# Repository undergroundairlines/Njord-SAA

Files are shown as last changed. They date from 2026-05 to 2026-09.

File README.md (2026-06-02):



# Njord-SAA
The Njord SAA (Submersible Amphibius Aircraft) is a submersible aircraft which can transition automatically from underwater travel to aerial flight. To resurface, it can empty it's 2 ballast tanks, pitch almost 90° directly up, and launch itself above the surface. When the surface is breached, it deploys 2 sets (yes, that means 4 wings total) of wings, and switches motors to a much higher RPM to produce enough thrust for flight.
The reason for this project was we thought a amphibius aircraft so we designed It. We always wanted a drone/plane and this was our best chance to get one.
Njord SAA v2
# Features 
* Deployable wings: The main visual feature of the Njord SAA is its wings, having 2 sets of deployable wings which allow having good hydrodynamics underwater, while still being able to produce enough lift to fly. The rear set of wings deploy forwards and meet the forward most wings at their tips.

* ~1.5:1 Thrust to Weight Ratio: Due to having 2 large 3 bladed props, and motors that are way too overpowered, at max thrust it will be able to produce mor than the crafts weight in thrust. This will make it incredibly fast, decently manouverable, and much cooler!

* Tailerons: Due to the wings being deployable, there is not enough room to house servos for the ailerons. No matter! Instead, we will repurpose the elevators (and possibly rudders as well) to do both pitch and roll.

* Auto Land: There will be a sort of Auto land feature to be added eventually, where at the flick of a button the craft can automatically bring itslef to the ground safely, and softly.

* Groud Avoidance System (GAS): Any time the pilot brings the aircraft too close to the ground, it will automatically pull up just before the perfect moment to ensure the pilot remains under control right until it's almost too late. Uses data from the gyro, and laser rangefinder to (semi-realistically) estimate its height, which allows the  computer to know when to pull up.

* As an opposite to the Ground Avoidance System, there will be a system to resurface the craft when submerged if the batteries become dangerously low, or it loses signal.

# CAD
The cad files for the Njord SAA were made in autodesk inventor professional. There are 5 seperate modules for the elevators, wings, tail, body and nose. There were lots of struggles with the cad on multiple occasions, such as how I had to fully redesign the body nose and tail a few times. The main reason for this was because I had very little design constraints to work from, and mostly figured it out as I went.

Nose cone:


Tail:


# PCB
This is the PCB for the Njord SAA! It is a standard 4 layer PCB featuring all elements needed for a flight computer like an IMU, barometer, an ESP32, and many pin headers for devices like servos, motors, and other sensors. It was designed originally in Eagle, but I switched to KiCad bacause there were a lot more sources for help, and it both looks and feels more modern.

Render top:


Wiring diagram:


Schematic:



  # How to buld

  ### !! MAKE SURE TO WEAR PROPER PPE WHEN WORKING ON CURED CARBON FIBER & FIBERGLASS !!
  (resperator and eye protection, full body suit for fiberglass)

 ### Prepare fuselage:
1. 3d print the main body, tail section, tail tip, nose cone, bulkhead, and hatches, then remove supports and clean up the prints
2. Lightly sand the nose cone and main body to ensure a proper adhesion to the epoxy
3. Cut carbon fiber weave to the correct size to wrap the main body, then cut out sections for the wing pins, ESC slots and battery hatches. Do the same for fiberglass to the nose cone
4. Make sure the cuts fit the subsequent part BEFORE mixing any epoxy
5. Mix 2 part epoxy in the correct ratio supplied by the manufacturer, then with a foam roller wet out cuts on both sides and squeeze out the excess epoxy
6. Wrap the carbon fiber around the body section, smooth out any wrinkles and air pockets, then apply peel ply to the surface. Repeate process for the fiberglass on the nose cone (peel ply is optional for fiberglass) and leave both to cure for 24-48 hours
7. After drying, drill out screw holes (you can shine a light through the holes in the 3d print to see the outline) and dremel the edges of the pre cut sections for wing pins and hatches until their sizes match the 3d print
 ### Prepare Control Surfaces & Wings:
1. 3d print rudders, elevons, and wings, then remove supports and clean up the prints
2. Lightly sand all surfaces of all parts for good adhesion, and pre cut carbon fiber weave to the correct sizes for each part seperately, with cutout areas for the wing bearings
3. Repeat steps 4-7 from the Fuselage Preperation instructions for each part
5. Cut 8mm carbon fiber rods so they will just stick out of the wing spar holes, there are 2 8mm rods in each of the four wings. Coat each rod with Sikaflex, then push as far into the hole as possible and let cure for 12-24 hours. After cured, cut the CF rods as close to the wing as possible and sand or file the rest until it is flush with the wing
6. Press fit a bearing into each wing in the provided slot
7. Repeat step 5, but with 5mm carbon fiber rod and for the back holes only in the elevators
### Install Electronic Hardware:
1. Neatly solder the PCB using the stencil provided by JLCPCB, and plug in the ESP32-S3 DEVKITC along with the MINI-560 buck converter. Make sure that the buck converter and esp32 are placed the correct way around, and test for improperly soldered components
2. Install the following hardware into their respective places:
   * Rear servos; Each servo is held in by 2 screws (make sure the cables get routed through the cable hole), then sealed using Sikaflex for waterproofing.
   * Motors; Install to motor mounts with 4 screws 
   * ESCs; Sikaflex each ESC into the slots, making sure they are facing the correct direction and wires are through the holes. Use more Sikaflex to create a flush surface over the ESCs for aerodynamics
   * Centre servo; Screw 2 screws into internal mount located on the rear of the body section. Connect to all 4 wings' release pins with push rods
   * Ballast Pumps; Slot pump into the slot and Sikaflex it into place. Heat insert the brass tube fittings into the wall holes and ballast tank holes, then connect tubing from pump input to the outside connecter, and the output to the connector on the ballast tank. Repeat for both pumps
   * Batteries: Slide in the two 5200mah batteries into the secure slot in the top and bottom hatches, ensuring the cables go towards the front
   * FS CVT01; Secure one side to the bottom of the forward part of the main body section using either hot glue, or Sikaflex
   * LiDaR; Insert LiDaR into the nose cone and Sikaflex it to solidify its position
   * PCB; Slot PCB into the tray inside the nose cone and screw the 2 screws into the corners
   * iA6B; Insert iA6B below the PCB, with the antenna facing forwards and pins pointing rearwards. Secure in place with hot glue, or Sikaflex
### Cable Routing:
##### Tip: lable each cable before installing so you know what  is what
1. Start with the tail section:
   * Rear servos; Route the servo's cable through the channel for them to bring them to the forwards most part of the tail, and connect a cable extender to the cable. Repeat for all 4 servos
   * Motors; Route the motor cables along the inset channels on the rear side of the motor mount and into the tail. Once into place, use Sikaflex to fill the rest of       the channel and the hole that enters the tail section. Solder and heatshrink a similar thickness cable to each of the 3 wires on the motor, and repeat for both motors
2. Main Body section:
   * ESCs; Route the wires through the holes that lead into the body, and seal the cable holes with Sikaflex. Connect the 3 pin cable to an extender and run it below the wing box to the front of the body, and repeat on the other side. Solder both ESCs' + and - input cables to a single xt-60 connector, making sure to put the + and - the correct way around. Attach an XT-60 cable extender (make it yourself with 2 spare wires and XT-60 connectors) to the plug, and run it down the body with the 3 pin cable
   * Centre Servo; Plug a servo cable extender into the connector, then run it internally below the wing box and out of the front of the body
   * Ballast Pumps; Strip the tip off of 2 spare wires, then twist them to the + and - of the pump. Solder a small amount of solder onto the connection to ensure good connection, then pull a piece of shrink wrap over the exposed wire and shrink with a heat gun. Repeat on both pumps
   * FS CVT01; Cut the connectors off of the two 1 pin cables, and solder them directly to the XT60 connector (make sure the polarity is correct)
3. Nose Cone:
   * LiDaR; Connect 5 pin cable to the "GY-TOF10M" labled 5 pin header on the pcb
   * iA6B; Plug a 3 pin cable into the "Servo" section on the iA6B, and connect it to the horizontal 3 pin header on the pcb. Optionally, you can shorten the  3 pin cable by cutting it to length, removing the connector, and re soldering it to the fixed length
### Final Assembly:
##### Connect tail section and main body:
 1. Solder and heatshrink the 3 motor cables to the matching 3 cables on the ESC. Repeat on both motors
 2. Route servo cables down the body section along with the cables already going that direction
 3. Slide the body section half way into the tail's slot, then lightly coat the inner wall of the outer rim of the tail section with Sikaflex and slide it fully in. Moving quickly, Screw in the tail section to the body through the 4 screw holes, placing a bead of Sikaflex below the screw's head before fully screwing it in
##### Install Bulkhead:
 1. Pass all loose cables hanging out of the body section through the hole in the bulkhead, and plug in the following cables to the PCB:
       * Servos; Servo plugs on the PCB are labled, and connect as follows: servo 1: left elevon, servo 2: right elevon, servo 3: top rudder, servo 4: bottom rudder, and servo 5: wing release servo
       * ESCs; 3 pin cables plug into "ESC_1" for left ESC and "ESC_2" for right ESC
       * Ballast Pumps; connect cables to screw terminals "Pump_1" and "Pump_2". It does not matter which side connects to which terminal
       * FS CVT01; DOES NOT PLUG INTO PCB, instead it plugs into the "sense" plug on the radio reciever
 2. Put bulkhead far enough from the nose to fit a screw driver to the 2 PCB screws, and pull all cables through the bulkhead to this length. Sikaflex the cable hole completely shut to prevent any leaking
 3. Insert O-ring into the groove in the nose cone and push the bulkhead into the nose cone. Screw in all 8 screws in a star pattern to fully seal the nose, with a bead of Sikaflex enderneath each screw's head
##### Attach nose cone to body:
 1. Drop a bead of Sikaflex onto the nose cone's outer rim and slide the body into the nose cone's slot.
 2. Screw in the 4 screws around the attachment area, with a bead of Sikaflex below each screw's head
##### Attach wings:
 1. Insert the wing into the wing slot, ensuring that the leading edge of the wing is facing outwards of the body
 2. Push an 8mm CF rod into the hole in the body that corresponds to the wing, and cut it down to a size where you can file the rest
##### Attach elevators and rudders:
 1. Place a 5mm CF rod loosely into the front hole of the left elevator
 2. Push the other side of the CF rod through the hole located just in front of the elevator servo, and place the right elevator on the other end of the CF rod
 3. Attach pushrods to both servos that attach to each elevator
 4. Slot rudders into the hinge joints located on the top and bottom of the tail, and insert a 2mm steel rod (you can cut up a push rod to use as this) into the hinge and   attach onto the hings with a small bead of Sikaflex
 5. Attach rudders to rudder servos with a push rod
##### Final attachments:
 1. Connect the props to the motors with the nut that screws into the motor shaft. Make sure the props are facing the correct way
 2. Attach the hatches by putting a small amount of Sikaflex around the channels on the body, then press them in
### Firmware:
 1. Download firmware from Github page
 2. Connect ESP32 to computer via the USB-C port on the ESP32
 3. Upload the firmware onto the board

### Conquer the seas and skies!

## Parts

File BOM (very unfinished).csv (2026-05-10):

Component | Model | Qty | Price Per Unit | Price Total | Link | Description
ESP32 | ESP32-S3 DEVKIT-C | x1 | $12.88 | $12.88 | AliExpress | Main Micro Controller
ESP32 CAM | ESP32-S3 CAM | x1 | $10.32 | $10.32 | AliExpress | Takes video feed from camera and both records it and transmits it
120° Camera | OV2640 w/120° lense | x1 | $12.38 | $12.38 | AliExpress | Camera for recording video
Brushless Motor | IFlight XING 2806.5 1300KV | x2 | $51.58 | $103.16 | AliExpress | Brushless motors for thrust
Servo 17G 4pc | SURPASS Hobby Waterproof Servo 17g | x1 | $46.00 | $46.00 | AliExpress | Servos for flight control surfaces
Avionics battery | 1800mah 2s LiPo | x1 | $17.66 | $17.66 | AliExpress | Battery for powering avionics flight computers & servos
ESC | HV Bidirectional 60A Brushless ESC | x2 | $24.91 | $49.82 | AliExpress | ESCs for main motors
Water Pump | MINI310 water pump | x2 | $7.83 | $15.66 | AlExpress | Water pumps for the ballast tanks
Barometer | BMP-280 | x1 | $7.94 | $7.94 | AliExpress | Measures borometric altitude & tempurature
IMU | MPU-6050 | x1 | $10.62 | $10.62 | AliExpress | Measures force angular momentum and orientation using gyroscopes and accelerometers
Laser Rangefinder | GY-TOF10M | x1 | $29.88 | $29.88 | AliExpress | Measures distance using LiDaR
Controller+Transceiver | Flysky FS-i6 + FS-IA6B | x1 | $79.69 | $79.69 | AliExpress | Controller and reciever for controlling craft
Voltage Monitor | INA219 | x1 | $4.64 | $4.64 | AliEpress | Measures the battery percentage of the avionics & servos battery
Buck Converter | Mini-560 | x1 | $4.60 | $4.60 | AliExpress | Converts the 2s LiPo voltage down to 5V for the ESP32s
Voltage Monitor | FS-CVT01 | x1 | $8.50 | $8.50 | AliExpress | Measures battery percentage of the main motor batteries
3D Printer Filament | 1KG PLA+ | x1 | $27.90 | $27.90 | JayCar | Main body material
Props | 3-Blade 7x3.7 Carbon Fiber Reinforced Pusher | x2 | $9.47 USD | $18.94 USD | MasterAirScrew | Propellers for the motors
Motor batteries | 5200mah 3s LiPo | x2 | FREE | N/A | Already Own | Batteries for the motors
Pump Motor Driver | L293D | x1 | FREE | N/A | Already Own | IC for the motors on the ballast tnk pumps
Epoxy Resin | 500ml 105 Resin 100ml 206 Slow Hardener | x1 | $35.00 | $47.50 | CarbonFibreNZ | Epoxy for carbon fiber wrap
PCB | N/A (custom) | x1 | $9.11 USD | $9.11 USD | JLCPCB | The main PCB for the board

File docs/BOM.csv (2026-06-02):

Component | Model | Qty | Price Per Unit (NZD) | Price Total (NZD) | Description | Link
ESP32 | ESP32-S3 DEVKIT-C | x1 | $13.20 | $13.20 | Main Micro Controller | https://www.aliexpress.com/item/1005009443835670.html?curPageLogUid=yhikXG2a50KB
ESP32 CAM | ESP32-S3 CAM | x1 | $10.36 | $10.36 | Takes video feed from camera and both records it and transmits it | https://www.aliexpress.com/item/1005009603118642.html?curPageLogUid=Ny8dmuNQDHgh
120° Camera | OV2640 w/120° lense | x1 | $13.04 | $13.04 | Camera for recording video | https://www.aliexpress.com/item/1005003040149873.html?curPageLogUid=EX1mAZmXkq9m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
Brushless Motor | IFlight XING 2806.5 1300KV | x2 | $52.43 | $104.86 | Brushless motors for thrust | https://www.aliexpress.com/item/1005005797059350.html?curPageLogUid=FrT1iZ1dkwSU
Servo 17G 4pc | SURPASS Hobby Waterproof Servo 17g | x1 | $54.89 | $54.89 | Servos for flight control surfaces | https://www.aliexpress.com/item/1005011970825050.html?curPageLogUid=urmbD6P5YXFl
Avionics battery | 1800mah 2s LiPo | x1 | $17.91 | $17.91 | Battery for powering avionics flight computers & servos | https://www.aliexpress.com/item/1005007182130611.html?curPageLogUid=40znlc1nTevL
ESC | HV Bidirectional 60A Brushless ESC | x2 | $28.67 | $28.67 | ESCs for main motors | https://www.aliexpress.com/item/1005008362023140.html?curPageLogUid=hjvrkB2vXBu2
Water Pump | MINI310 water pump | x2 | $8.34 | $16.68 | Water pumps for the ballast tanks | https://www.aliexpress.com/item/1005006370254024.html?curPageLogUid=tNk3NmLuvTD3
Barometer | BMP-280 | x1 | $8.03 | $8.03 | Measures borometric altitude & tempurature | https://www.aliexpress.com/item/1005006145809829.html?curPageLogUid=gTsKcyiu9Wgb
IMU | MPU-6050 | x1 | $10.74 | $10.74 | Measures angular momentum and orientation using gyroscopes and accelerometers | https://www.aliexpress.com/item/1005007986741850.html?curPageLogUid=WiZY28EeYpG7
Laser Rangefinder | GY-TOF10M | x1 | $34.08 | $34.08 | Measures distance using LiDaR | https://www.aliexpress.com/item/1005010057040406.html?curPageLogUid=LV2Zd7n8UNBZ&tblci=GiicPeIDQBGn
Controller+Transceiver | Flysky FS-i6X mode 1 + FS-IA6B | x1 | $92.23 | $92.23 | Controller and reciever for controlling the craft | https://www.aliexpress.com/item/1005008563775706.html
Carbon Fiber Rod | 8mm diameter CF rod | x1 | $21.22 | $21.22 | Structural support for wings and control surfaces | https://www.aliexpress.com/item/1005005928525467.html?mp=1
Carbon Fiber Rod | 5mm diameter CF rod | x1 | $19.42 | $19.42 | Structural support for wings and control surfaces | https://www.aliexpress.com/item/1005005928525467.html?mp=1
Voltage Monitor | INA219 | x1 | $4.68 | $4.68 | Measures the battery percentage of the avionics & servos battery | https://www.aliexpress.com/item/1005006962623981.html?curPageLogUid=pcRlKCNUlJnC
Buck Converter | Mini-560 | x1 | $4.88 | $4.88 | Converts the 2s LiPo voltage down to 5V for the ESP32s | https://www.aliexpress.com/item/1005007937920693.html?curPageLogUid=jG9JrBtyCWHu
Voltage Monitor | FS-CVT01 | x1 | $10.24 | $10.24 | Measures battery percentage of the main motor batteries | https://www.aliexpress.com/item/1005005655589326.html?curPageLogUid=gV7MOMrktYzM
Carbon Fiber Cloth | 3K 200gsm 50cm x 100cm CF cloth | x1 | $36.37 | $36.37 | Reinforces main body wings and control surfaces while also making it look cooler | https://www.aliexpress.com/item/1005007348624832.html?curPageLogUid=uryVPGNNJrr8&tblci=GiicPeIDQBGn
Fiberglass Cloth | 100gsm 1m x 1m Fiberglass Cloth | x1 | $18.14 | $18.14 | Reinforces nose cone without blocking the RF from controller | https://www.aliexpress.com/item/1005008036317872.html?curPageLogUid=9zYmTFLXnU9l&tblci=GiicPeIDQBGn
Servo Extension Cables | 3 pin 2.54mm cable | x1 | $13.08 | $13.08 | Extends 3 pin cable from rear of aircraft to the electronics up front | https://www.aliexpress.com/item/1005010517334911.html?curPageLogUid=0LW6TJ8GmtHB&tblci=GiicPeIDQBGn
Battery series merger | XT60 2M to 1F series connector | x1 | $6.55 | $6.55 | Combines both 3s LiPos in series to simulate a single 6s | https://www.aliexpress.com/item/1005011999351493.html?curPageLogUid=XiVO3nLWUS7M&tblci=GiicPeIDQBGn
Screws | M3 hex screws | x1 | $5.44 | $5.44 | Used to screw together the body panels motors and bulkhead | https://www.aliexpress.com/item/1005011845940916.html?curPageLogUid=pJrlIQslEdqR&tblci=GiicPeIDQBGn
Nuts | M3 Nuts | x1 | $4.99 | $4.99 | Put on other side of screws to screw into | https://www.aliexpress.com/item/4001007279182.html?curPageLogUid=NLEZbsVWeS4W&tblci=GiicPeIDQBGn
O-Ring | 53x49x2 Rubber O-ring seal | x1 | $5.34 | $5.34 | Seals the removoable nose cone | https://www.aliexpress.com/item/1005002906519719.html?curPageLogUid=FkbyOexOq9Nm
Servo Push Rods | 1.2mm Z-style push rods | x1 | $3.82 | $3.82 | Connects servos to control surfaces | https://www.aliexpress.com/item/1005006611756914.html?curPageLogUid=gV3I7OYUeuq5&tblci=GiicPeIDQBGn
Pump Motor Driver | L293D | x1 | $3.93 | $3.93 | IC for controlling the ballast pumps | https://www.aliexpress.com/item/1005010400118009.html?curPageLogUid=t7r7pJhS8Kq1&tblci=GiicPeIDQBGn
Battery conectors | XT60 M & F Connectors | x1 | $6.46 | $6.46 | Used to make cables that connect to the batteries | https://www.aliexpress.com/item/1005006707752699.html?curPageLogUid=R3h81IFLTU0t&tblci=GiicPeIDQBGn
3D Printer Filament | 1KG Elegoo White Rapid PLA+ | x1 | $29.90 | $29.90 | Main body material | https://jaycar.co.nz/elegoo-rapid-pla-filament-white-1-75mm-1kg/p/TL6436
Props | 3-Blade 7x3.7 Carbon Fiber Reinforced Pusher | x2 | $9.47 USD | $18.94 USD | Propellers for the motors | https://www.masterairscrew.com/products/3mr-series-3-blade-7x3-7-propeller-cw-rev-pusher-carbon-fiber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
Motor batteries | 5200mah 3s LiPo | x2 | FREE | N/A | Batteries for the motors | Already Own
Epoxy Resin | 500ml 105 Resin 100ml 206 Slow Hardener | x1 | $35.00 | $47.50 | Epoxy for carbon fiber wrap | https://carbonfibre.co.nz/categories/epoxy-resin/600ml-pack-500ml105-resin-100ml-206-slow-hardener/
Adhesive | Sikaflex 291 | x1 | $22.88 | $22.88 | Marine grade adhesive for water proofing and gluing | https://mitre10.co.nz/shop/sika-marine-sealant-adhesive-70-ml-black/p/303969
PCB | 4 layer 1oz copper internal + Stencil | x1 | $30.6USD | $30.6 | The main PCB for the project | https://cart.jlcpcb.com/quote?stencilLayer=2&stencilWidth=100&stencilLength=100&stencilCounts=5&plateType=1
TOTAL Inc Shipping (NZD) | $746.09 |  | !! This price does not include items already listed in USD !!
TOTAL Inc Shipping (USD) | $521.17

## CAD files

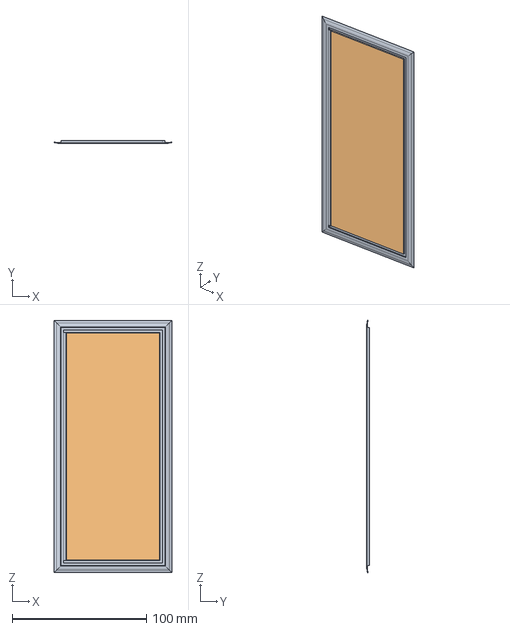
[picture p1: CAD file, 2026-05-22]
CAD/Hatch_Bottom.stp
88.0 x 2.50 x 188.0 mm

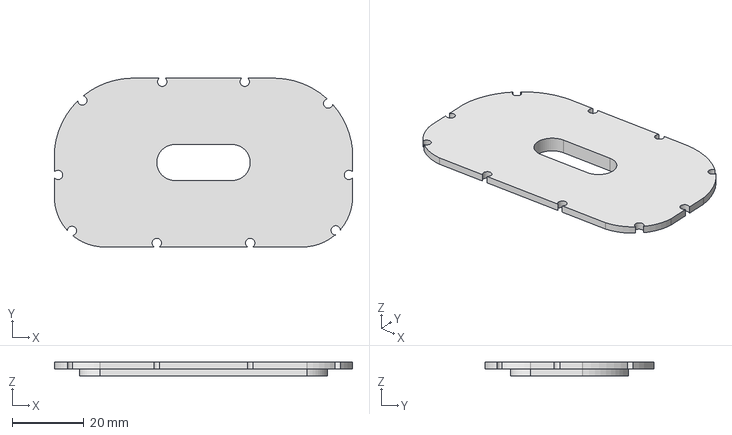
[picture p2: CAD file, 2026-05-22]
CAD/Nose_Bulkhead.stp
83.0 x 47.0 x 4.00 mm

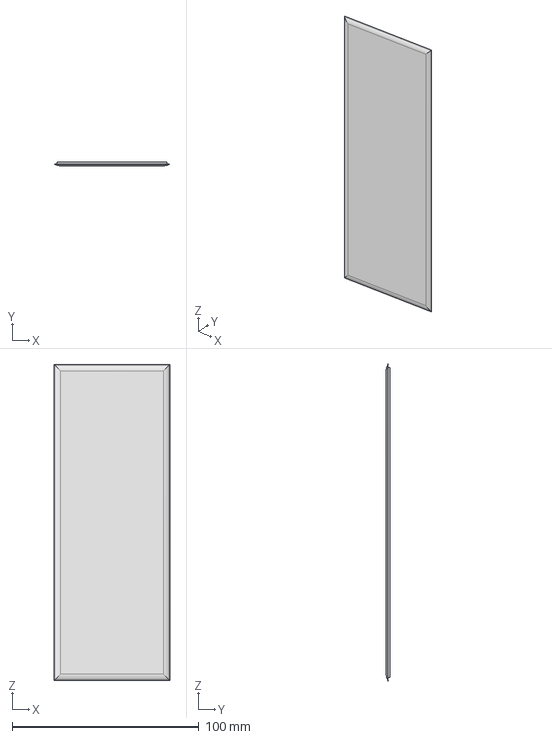
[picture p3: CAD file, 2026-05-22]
CAD/Hatch_Top.stp
62.0 x 2.00 x 169.0 mm

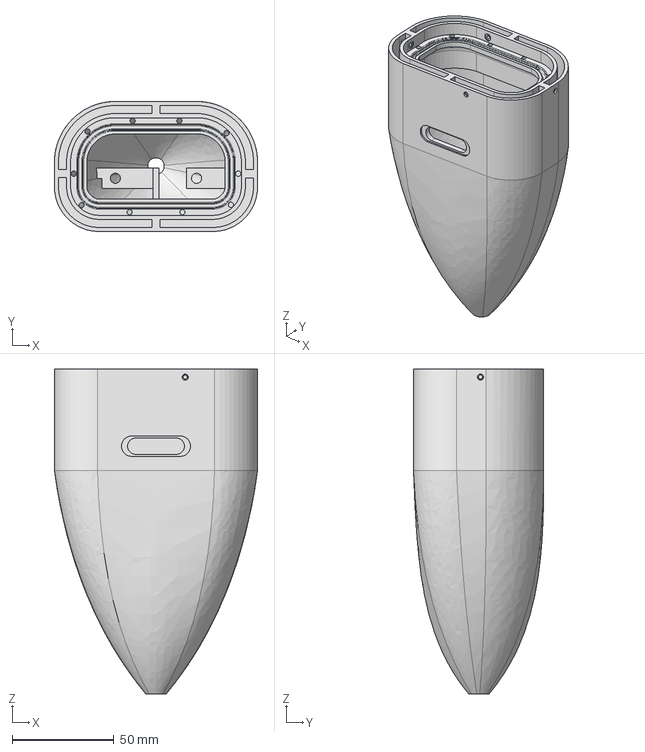
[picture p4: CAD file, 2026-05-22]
CAD/Nose.stp
100.0 x 64.0 x 160.0 mm

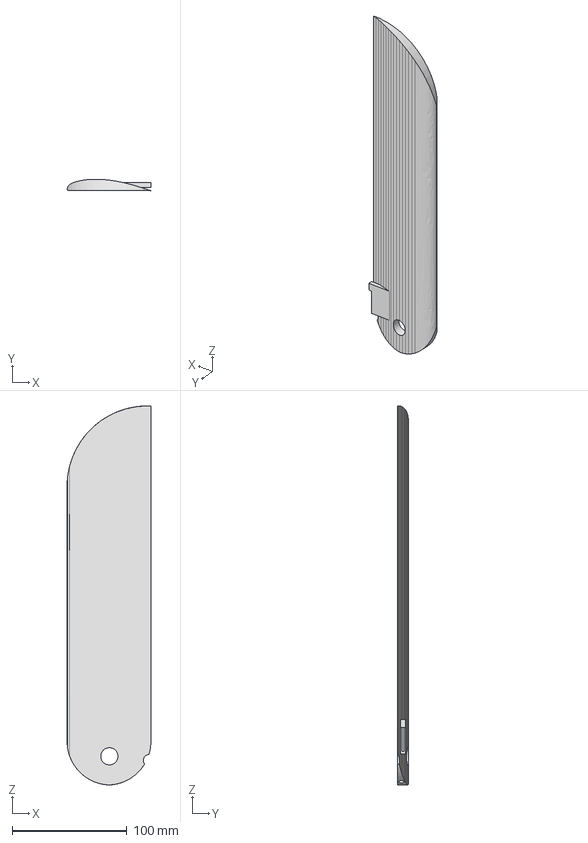
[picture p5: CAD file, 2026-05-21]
CAD/Front_Wings.stp
72.9 x 9.96 x 330.0 mm

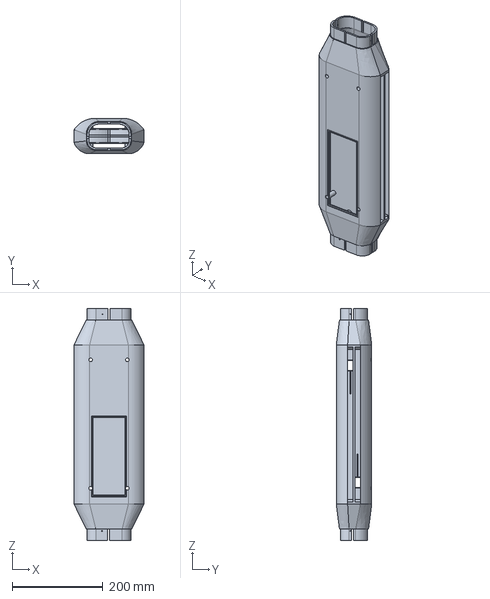
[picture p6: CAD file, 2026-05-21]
CAD/Body.stp
154.0 x 78.0 x 510.0 mm

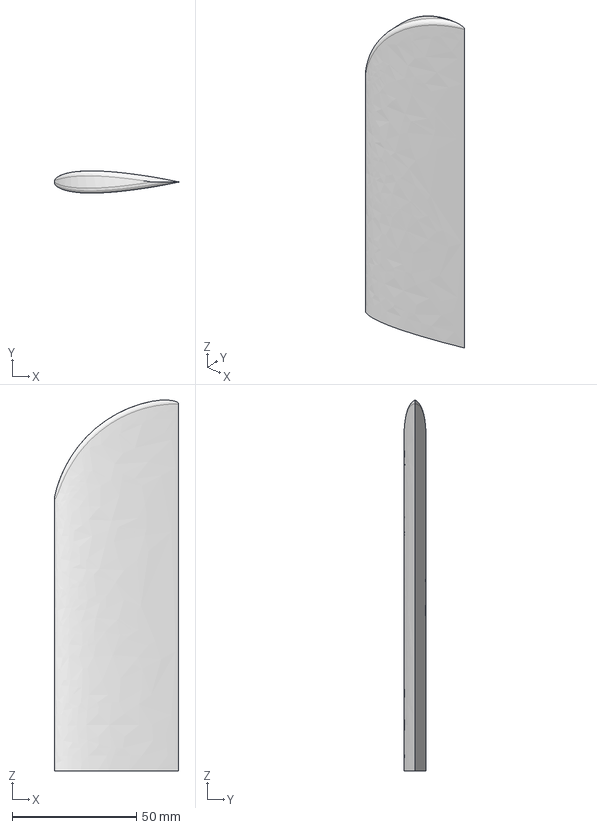
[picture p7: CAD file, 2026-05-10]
CAD/Elevons.stp
50.2 x 9.02 x 149.6 mm

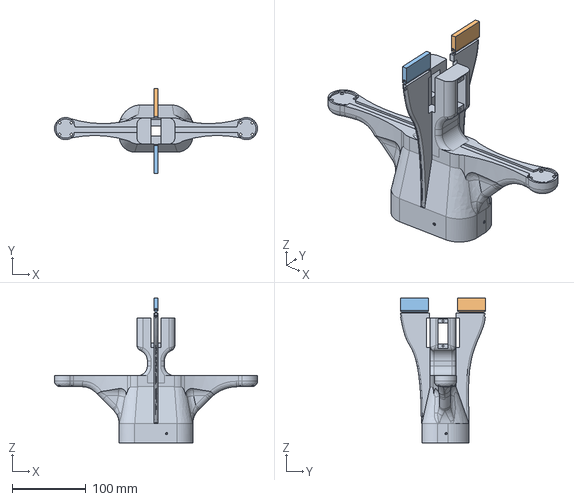
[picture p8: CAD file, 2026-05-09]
CAD/Tail.stp
274.9 x 115.0 x 196.0 mm

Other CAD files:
CAD/IPTs/fork.stp
CAD/IPTs/Body Section.ipt
CAD/IPTs/Elevons.ipt
CAD/IPTs/Hatch_Bottom.ipt
CAD/IPTs/Hatch_Top.ipt
CAD/IPTs/Tail Tip.ipt
CAD/IPTs/Tail.ipt
CAD/IPTs/Wings_Rear.ipt
CAD/nosio holio blky.ipt

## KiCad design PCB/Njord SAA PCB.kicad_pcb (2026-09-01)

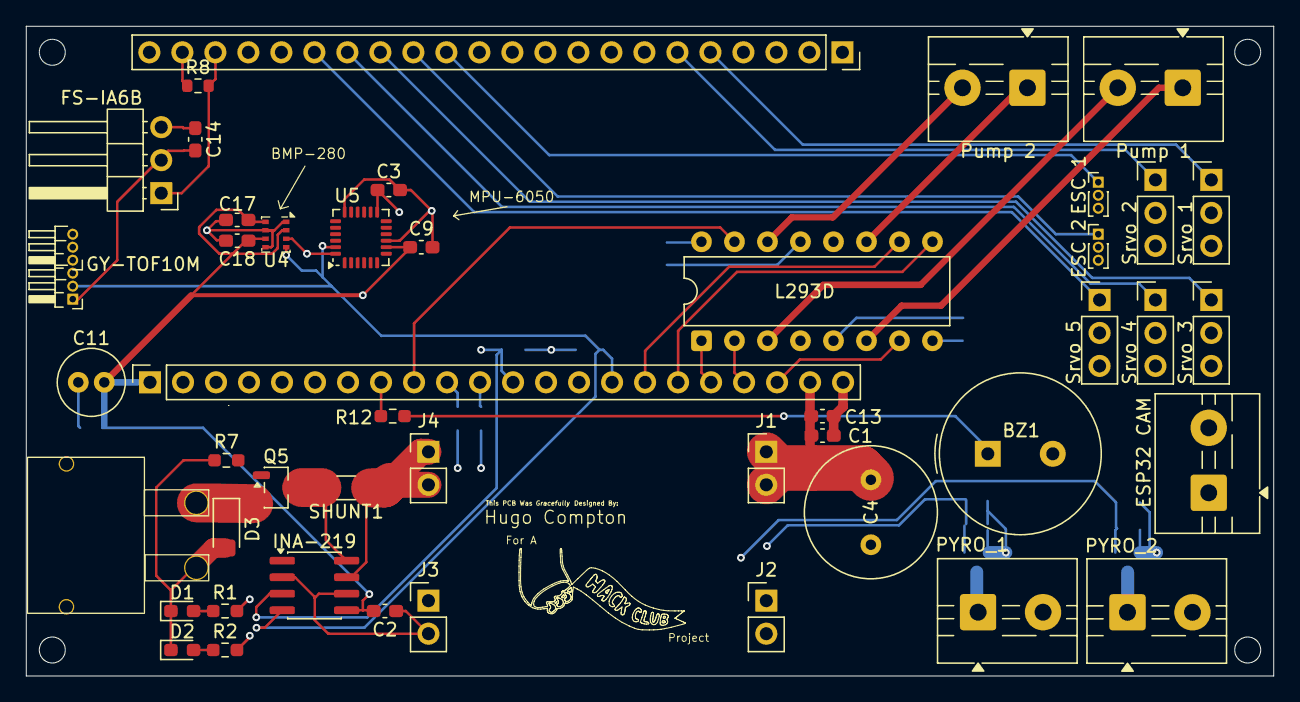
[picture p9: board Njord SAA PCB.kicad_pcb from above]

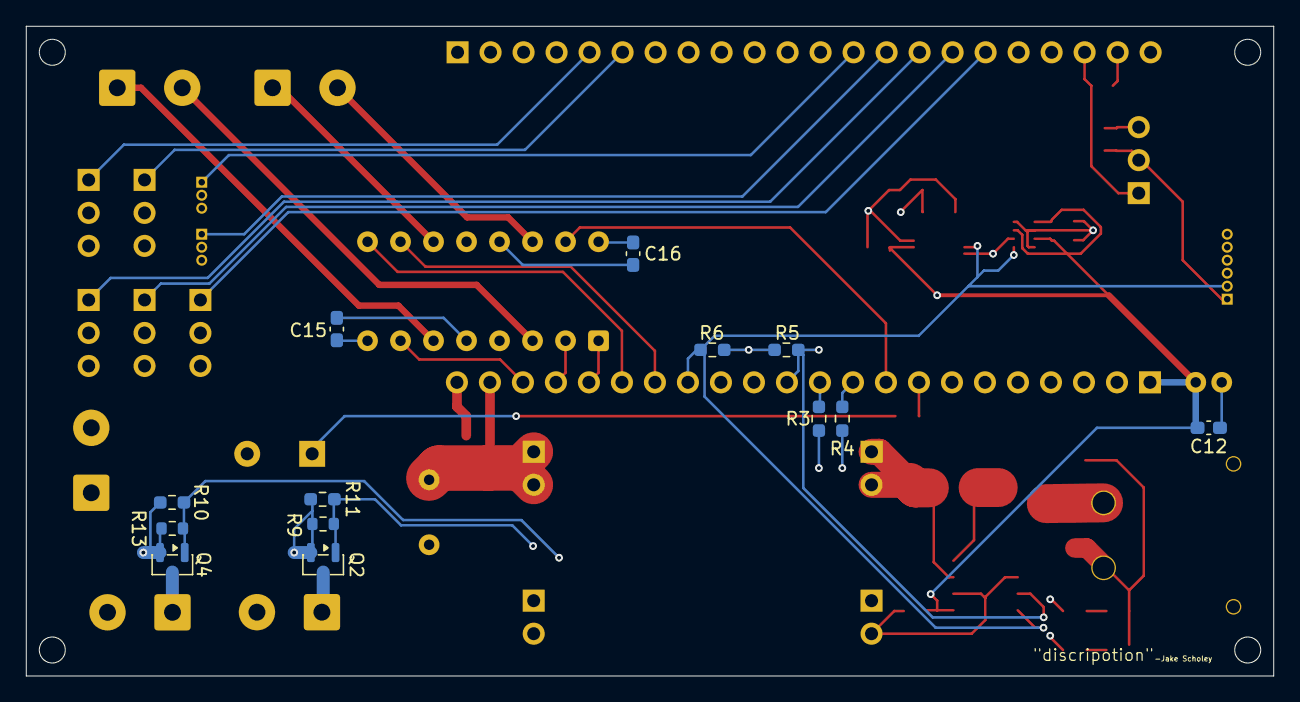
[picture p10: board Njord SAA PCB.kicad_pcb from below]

Board: 4 copper layers, 96.0 x 50.0 mm, 60 parts (13 on the bottom side), 40 nets.

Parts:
BZ1: Buzzer; Buzzer_TDK_PS1240P02BT_D12.2mm_H6.5mm
C1: 1uF; C_0603_1608Metric_Pad1.08x0.95mm_HandSolder
C2, C3, C9, C12, C13, C14, C16, C17, C18: 0.1uF; C_0603_1608Metric_Pad1.08x0.95mm_HandSolder
C4: 1000uF; C_Radial_D10.0mm_H20.0mm_P5.00mm
C11: 68uF; C_Radial_D5.0mm_H11.0mm_P2.00mm
C15: 10uF; C_0603_1608Metric_Pad1.08x0.95mm_HandSolder
D1: GRN LED; LED_0603_1608Metric_Pad1.05x0.95mm_HandSolder
D2: RED LED; LED_0603_1608Metric_Pad1.05x0.95mm_HandSolder
D3: SMF10A; D_SMF
ESC 1, ESC 2: Conn_01x03_Pin; PinHeader_1x03_P1.00mm_Vertical
ESP32, ESP32_L1: Conn_01x22_Socket; PinSocket_1x22_P2.54mm_Vertical
ESP32 CAM: Screw_Terminal_01x02; TerminalBlock_MaiXu_MX126-5.0-02P_1x02_P5.00mm
FS-IA6B: Conn_01x03_Pin; PinHeader_1x03_P2.54mm_Horizontal
GY-TOF10M: Conn_01x03_Pin; PinHeader_1x03_P1.00mm_Horizontal
INA-219: INA219AxD; SOIC-8_3.9x4.9mm_P1.27mm
J1: V+OUT; PinHeader_1x02_P2.54mm_Vertical
J2: V-OUT; PinHeader_1x02_P2.54mm_Vertical
J3: V-IN; PinHeader_1x02_P2.54mm_Vertical
J4: V+IN; PinHeader_1x02_P2.54mm_Vertical
J7: Conn_01x03_Pin; PinHeader_1x03_P1.00mm_Horizontal
L293D: L293; DIP-16_W7.62mm
PYRO_1, PYRO_2: Screw_Terminal_01x02; TerminalBlock_MaiXu_MX126-5.0-02P_1x02_P5.00mm
Pump 1: Ballast Pump 1; TerminalBlock_MaiXu_MX126-5.0-02P_1x02_P5.00mm
Pump 2: Ballast Pump 2; TerminalBlock_MaiXu_MX126-5.0-02P_1x02_P5.00mm
Q2, Q4: Si2302; SOT-23
Q5: Q_PMOS_GSD; SOT-23-3
R1, R3, R4, R12: 100R; R_0603_1608Metric_Pad0.98x0.95mm_HandSolder
R2: 220R; R_0603_1608Metric_Pad0.98x0.95mm_HandSolder
R5, R6: 4.7kR; R_0603_1608Metric_Pad0.98x0.95mm_HandSolder
R7: 100kR; R_0603_1608Metric_Pad0.98x0.95mm_HandSolder
R8: 1kR; R_0603_1608Metric
R9, R13: 10kR; R_0603_1608Metric
R10, R11: 10kR; R_0603_1608Metric_Pad0.98x0.95mm_HandSolder
SHUNT1: 10mR; R_1206_3216Metric_Pad1.30x1.75mm_HandSolder
Srvo 1, Srvo 2, Srvo 3, Srvo 4, Srvo 5: Motor_Servo; PinHeader_1x03_P2.54mm_Vertical
U3: 2s LiPo Connector; XT-30
U4: BMP280; Bosch_LGA-8_2x2.5mm_P0.65mm_ClockwisePinNumbering
U5: MPU-6050; InvenSense_QFN-24_4x4mm_P0.5mm

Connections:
+3.3V: C2.2, C3.1, C9.1, C11.2, C12.2, C17.1, C18.1, ESP32_L1.1, INA-219.5 (VS), R5.1, R6.2, U4.2 (CSB), U4.6 (VDDIO), U4.8 (VDD), U5.8 (VLOGIC), U5.13 (VDD)
+5V: C1.1, C4.1, C13.1, C14.2, C15.1, C16.2, ESP32 CAM.1, ESP32_L1.21, FS-IA6B.2, GY-TOF10M.1, J1.1, J1.2, L293D.8 (VCC2), L293D.16 (VCC1), PYRO_1.2, PYRO_2.2, Srvo 1.2 (+), Srvo 2.2 (+), Srvo 3.2 (+), Srvo 4.2 (+), Srvo 5.2 (+)
/1A: ESP32_L1.19, L293D.2 (1A)
/2A: ESP32_L1.20, L293D.7 (2A)
/3A: ESP32_L1.16, L293D.10 (3A)
/4A: ESP32_L1.9, L293D.15 (4A)
/BUZZER: ESP32_L1.8, R12.2
/Ballast Pump 1 +: L293D.3 (1Y), Pump 1.2
/Ballast Pump 1 -: L293D.6 (2Y), Pump 1.1
/Ballast Pump 2 +: L293D.11 (3Y), Pump 2.1
/Ballast Pump 2 -: L293D.14 (4Y), Pump 2.2
/EN1,2: ESP32_L1.18, L293D.1 (EN1,2)
/EN3,4: ESP32_L1.17, L293D.9 (EN3,4)
/ESC_1: ESC 1.1, ESP32.13
/ESC_2: ESC 2.1, ESP32.14
/GRN LED: ESP32_L1.4, R1.2
/PYRO 1: ESP32_L1.11, R3.2
/PYRO 2: ESP32_L1.10, R4.2
/RED LED: ESP32_L1.5, R2.2
/RX: ESP32.20, FS-IA6B.1, R8.2
/SCL: ESP32_L1.15, GY-TOF10M.2, INA-219.4 (SCL), R6.1, U4.4 (SCK), U5.23 (SCL)
/SDA: ESP32_L1.12, GY-TOF10M.3, INA-219.3 (SDA), R5.2, U4.3 (SDI), U5.24 (SDA)
/Servo 1: ESP32.5, Srvo 1.1 (PWM)
/Servo 2: ESP32.6, Srvo 2.1 (PWM)
/Servo 3: ESP32.15, Srvo 3.1 (PWM)
/Servo 4: ESP32.16, Srvo 4.1 (PWM)
/Servo 5: ESP32.17, Srvo 5.1 (PWM)
/TX: ESP32.21, R8.1
GND: BZ1.2 (-), C1.2, C2.1, C3.2, C4.2, C9.2, C11.1, C12.1, C13.2, C14.1, C15.2, C16.1, C17.2, C18.2, D1.1 (K), D2.1 (K), D3.2 (A2), ESC 1.3, ESC 2.3, ESP32.1, ESP32.2, ESP32.22, ESP32 CAM.2, ESP32_L1.22, FS-IA6B.3, INA-219.2 (A0), INA-219.6 (GND), J2.1, J2.2, J3.1, J3.2, J7.3 (Pin_3_3), L293D.4 (GND), L293D.5 (GND), L293D.12 (GND), L293D.13 (GND), Q2.2 (S), Q4.2 (S), R7.1, R9.1, R10.2, R11.2, R13.1, Srvo 1.3 (-), Srvo 2.3 (-), Srvo 3.3 (-), Srvo 4.3 (-), Srvo 5.3 (-), U3.4 (V-_OUT), U4.1 (GND), U4.5 (SDO), U4.7 (GND), U5.9 (AD0), U5.18 (GND)
unnamed: BZ1.1 (+), R12.1
unnamed: D1.2 (A), R1.1
unnamed: D2.2 (A), R2.1
unnamed: D3.1 (A1), Q5.2 (S), U3.3 (V+_OUT)
unnamed: INA-219.7 (IN-), J4.1, J4.2, SHUNT1.1
unnamed: PYRO_1.1, Q2.3 (D)
unnamed: PYRO_2.1, Q4.3 (D)
unnamed: Q2.1 (G), R3.1, R9.2, R11.1
unnamed: Q4.1 (G), R4.1, R10.1, R13.2
unnamed: INA-219.8 (IN+), Q5.3 (D), SHUNT1.2
unnamed: Q5.1 (G), R7.2

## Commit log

2026-05-09 Update and rename BOM.csv to BOM (very unfinished).csv
    [BOM (very unfinished).csv]
2026-05-10 Update BOM (very unfinished).csv
    [BOM (very unfinished).csv]
2026-05-10 Rename BOM (very unfinished).csv to BOM.csv
    [BOM.csv]
2026-05-28 Rename wing ready for torsiom WITH COOKIE .stp to Front_Wings.stp
    [Front_Wings.stp]
2026-05-28 Rename BULK HEAD with half holes.stp to Nose Bulkhead.stp
    [Nose Bulkhead.stp]
2026-05-28 Rename big door slotty with toly rinces .5.stp to Bottom Hatch.stp
    [Bottom Hatch.stp]
2026-05-28 Rename top hatchy mo bob.stp to Hatch_Top.stp
    [Hatch_Top.stp]
2026-05-28 Rename Nose Bulkhead.stp to Nose_Bulkhead.stp
    [Nose_Bulkhead.stp]
2026-05-28 Rename Bottom Hatch.stp to Hatch_Bottom.stp
    [Hatch_Bottom.stp]
2026-05-28 Rename I think done body unless hugo hass a hissy fit part 1 .stp to Body.stp
    [Body.stp]
2026-05-29 Rename refinded nose cone with holes.stp to Nose.stp
    [Nose.stp]
2026-05-29 Rename FULL VIRTICAL NO HORISONTAL.stp to Tail.stp
    [Tail.stp]
2026-06-02 Rename CAD FILES/I think done body unless hugo hass a hissy fit.ipt to CAD FILES/IPTs/Body Section.ipt
    [Body Section.ipt]
2026-06-02 Rename CAD FILES/elivators s.ipt to CAD FILES/IPTs/Elevons.ipt
    [Elevons.ipt]
2026-06-02 Rename CAD FILES/FULL VIRTICAL NO HORISONTAL.ipt to CAD FILES/IPTs/Tail .ipt
    [FULL VIRTICAL NO HORISONTAL.ipt, Tail .ipt]
2026-06-02 Rename CAD FILES/back wings smooth .ipt to CAD FILES/IPTs/Wings_Rear.ipt
    [Wings_Rear.ipt]
2026-06-02 Rename CAD FILES/big door slotty with toly rinces .5.ipt to CAD FILES/IPTs/Hatch_Bottom.ipt
    [Hatch_Bottom.ipt]
2026-06-02 Rename CAD FILES/tail needs servo plug.ipt to CAD FILES/IPTs/Tail Tip.ipt
    [Tail Tip.ipt]
2026-06-02 Rename CAD FILES/top hatchy mo bob.ipt to CAD FILES/IPTs/Hatch_Top.ipt
    [Hatch_Top.ipt]
2026-06-02 Rename CAD FILES/wing ready for torsiom WITH COOKIE .ipt to CAD FILES/IPTs/Wing_Front
2026-06-02 Rename Tail .ipt to Tail.ipt
    [Tail.ipt]
2026-06-02 Re-arranged & Renamed the files and folder
    [BOM.csv, Body Section.ipt, Body.stp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]
2026-09-01 Replaced Wiring diagram and Render with new version
2026-09-01 Replaced schematic photo with updated one
2026-09-01 Replaced old PCB files with new & improved ones
    [Njord SAA PCB.kicad_pcb, Njord SAA PCB.kicad_sch]
2026-09-01 Added new Gerbers
